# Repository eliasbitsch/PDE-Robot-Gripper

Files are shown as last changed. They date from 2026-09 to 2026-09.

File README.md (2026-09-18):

# Robot Gripper - Part B

A two-finger gripper for an automated production cell, designed as a semester
project for *Produktdesign und Produktentwicklung*, MRE WS 2026/27.

A robot picks a PA 6 part off a buffer belt at 1000 mm, carries it 1800 mm and
places it on a workpiece carrier at 1300 mm. Cycle time is 5 seconds per part.
The part is given; the gripper is not.

**Team:** Bitsch Elias · Ovdiienko Viktoriia - Group 10
**Plan:** [PLAN.md](PLAN.md) · **Status:** concept phase, design freeze 4 Oct 2026

---

## 🔩 The part

| | |
|---|---|
| Bounding box | 95 × 100 × 80 mm |
| Volume | 528.5 cm³ |
| Material | PA 6, ρ = 1140 kg/m³ |
| Mass | 0.602 kg |
| Surface | Ra 1.6 |

Two flat, parallel side faces 70 mm apart, 6200 mm² on the smaller side. The
assignment allows gripping **from the side only** - no undergripping on the
belt, which rules out both a vacuum cup and anything that reaches underneath.

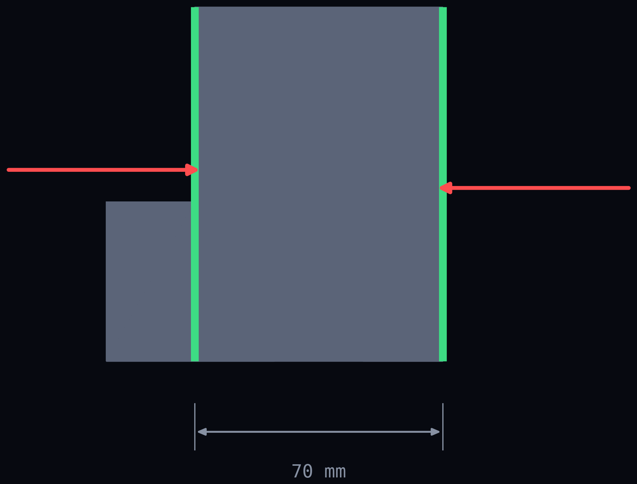
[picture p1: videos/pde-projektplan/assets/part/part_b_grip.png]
Top view of part B with both grip faces marked


---

## The concept

A **2-finger parallel gripper**, one **four-bar parallelogram per finger**,
driven by a single **servo motor** through a self-locking screw.

The design is **inspired by the Robotiq 2F-85**: electric, two fingers, one
four-bar per finger, pads that stay parallel. What we do not take over is its
underactuated adaptive wrap - in encompassing mode that is statically
indeterminate, and on two flat faces it buys nothing.

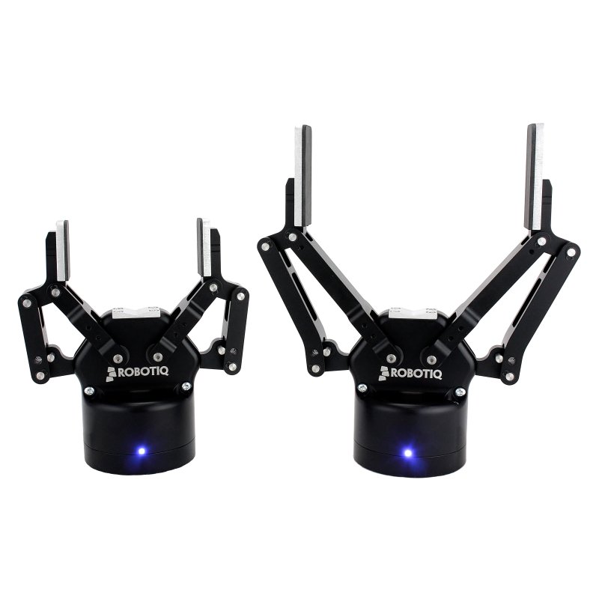
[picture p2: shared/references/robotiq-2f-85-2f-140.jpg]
Robotiq 2F-85 and 2F-140 adaptive grippers


*Robotiq 2F-85 and 2F-140. Photo: Robotiq Inc., used as a design reference.*

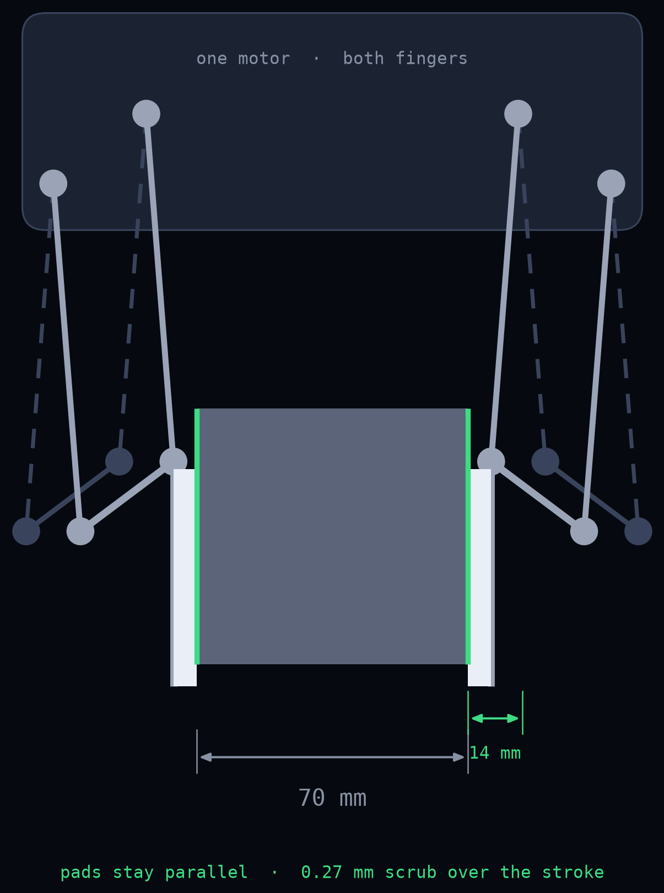
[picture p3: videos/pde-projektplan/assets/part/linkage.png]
Our four-bar linkage, open and closed


*Our version: links 90 mm, swing +-4.46 degrees, 14 mm stroke per side.*

Why this and not a rack:

- **Pads stay parallel** through the four-bar, so the flat faces stay in full contact
- **The screw is self-locking** - the part holds on power failure, no brake needed
- The tip travels on an arc, but with 90 mm links and ±4.46° of swing that is
  **0.27 mm of scrub** over the full 14 mm stroke per side

The price, stated honestly: jaw force is **not constant** over the stroke. The
worst transmission angle has to be proven, not assumed.

**Required gripping force:** 14.3 N per jaw (µ = 0.5 NBR/PA 6, safety factor 2.0,
path acceleration 2.05 m/s² out of the cycle-time budget).

---

## 🤖 The cell

Robot is an **ABB IRB 1600-6/1.45**. The interesting finding from the placement
study: with the robot centred on the floor the sequence is **not executable** -
not because of reach, but because of axis 5 (±115°). With the arm extended high
and far the forearm points steeply up and the tool can no longer be brought
vertical. The fix is a **500 mm pedestal plus a 100 mm base offset** toward the
workpiece carrier. That goes into the report as a finding, not hidden.

---

## 🛠 Toolchain

| Tool | Used for |
|---|---|
| **Onshape** | parametric CAD and FEM on the same model |
| **LaTeX** | calculations and the written report |
| **MuJoCo** | motion sequence, collision check, contact forces |
| **build123d / gmsh / CalculiX** | scripted geometry and the independent FEM cross-check |
| **FDM printing** | a printed jaw, loaded and measured, as a third data point against the FEM |

---

## Repository layout

```
├─ Elias/            system & numerical proof
├─ Viktoriia/        design & analytical proof
├─ shared/
│  ├─ submission/    final structure per Fig. 2 - German names, prescribed
│  └─ references/
├─ videos/           plan pitch video (HyperFrames)
├─ cad/ fem/ sim/    preliminary script chain, kept as reference
└─ PLAN.md
```

Each of us commits only inside our own folder, so there are no merge conflicts.
Merging happens once, at the end, in `shared/submission/`.

The four folder names under `shared/submission/` stay German on purpose - the
assignment prescribes that structure verbatim.

---

## 📅 Dates

| | |
|---|---|
| Design freeze | 4 Oct 2026 |
| Interim report | **26 Nov 2026** |
| Final review | **15 Jan 2027** |

Both are BB-1 dates. We are in different course groups and run on the earlier
schedule deliberately - see open point 0 in the plan.

---

## Grading

100 points across nine packages. The 3D design carries 20 on its own, every
other package 10. The full breakdown, the milestone plan and the open questions
are in [PLAN.md](PLAN.md).

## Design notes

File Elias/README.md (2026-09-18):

# Elias - system & numerical proof

Working area of Bitsch Elias. See [PLAN.md](../PLAN.md), § 5.

| Folder | Package | Result |
|---|---|---|
| `01_Robot` | E1 | Robot selection, placement study (500 mm pedestal + 100 mm base offset), reachability proof |
| `02_CAD_Body` | E2 | Housing, drive unit (servo + self-locking screw), four-bar with bearings, quick-change coupler, robot flange |
| `03_Drawing` | E3 | A3 assembly drawing + BOM |
| `04_Simulation` | E4 | MuJoCo model, path pick -> place, collision log, sequence video |
| `05_FEM` | E5 | Mesh, boundary conditions, mesh convergence, stress and deflection; compared against V4 |

Plus E6: infrastructure (repo, Onshape document, MCP integration, parameter table) in `../shared/`.

**Interface to Viktoriia:** the mounting plane carrier <-> jaw.
Frozen from week 41, changes only together.

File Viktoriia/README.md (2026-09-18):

# Viktoriia - design & analytical proof

Working area of Ovdiienko Viktoriia. See [PLAN.md](../PLAN.md), § 5.

| Folder | Package | Result |
|---|---|---|
| `01_Concept` | V1 | Variant comparison (VDI 2225) incl. the Robotiq 2F-85 as commercial reference and vacuum as a reasoned rejection, dimensioned concept sketch |
| `02_Sizing` | V2 | Gripping force, friction coefficient with a source, surface pressure on PA 6, four-bar via virtual work incl. worst transmission angle, screw and motor selection |
| `03_CAD_Jaws` | V3 | Jaws + soft pads, parametric in Onshape |
| `04_Analytical` | V4 | Bending stress and deflection by hand - the reference the FEM has to meet |
| `05_Print_Check` | V5 | Print the jaw, measure deflection under a defined load, hold it against Elias' FEM |

**The thread:** you design the jaws, work them out by hand, and then check the
FEM against a printed part. V3 -> V4 -> V5 is one chain.

**Interface to Elias:** the mounting plane carrier <-> jaw.
Frozen from week 41, changes only together.

**If something does not suit you:** § 10 in PLAN.md. V3<->E2 and V4<->E5 are cut
to be exchangeable on purpose.

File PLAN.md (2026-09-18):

# Project Plan - Robot Gripper, Part B

**Course:** Produktdesign und Produktentwicklung, MRE WS 2026/27
**Group:** 10 · **Part:** B (PA 6, Ra 1.6)
**Team:** Bitsch Elias · Ovdiienko Viktoriia
**Course groups:** split (BB-1 / BB-2) - interim report and final submission run **together on BB-1**
**Status:** 18 Sep 2026 - proposal, not yet agreed

> **Working language is English** - this plan, the repo, folder names and commit
> messages. Two exceptions, both deliberate: the submission folder names under
> `shared/submission/` stay **German**, because the assignment prescribes them
> verbatim; and the language of the submitted report itself still has to be
> confirmed with Saliger (see open point 5).

---

## 1. What this is

A robot picks part B off the buffer belt (1000 mm), travels 1800 mm
horizontally and places it on a workpiece carrier (1300 mm). Cycle time 5 s per
part. We design the gripper for it - the part itself is given and is not
modified.

Nine deliverables, listed in § 3, submitted in the folder structure from Fig. 2
of the assignment.

---

## 2. Technical decisions

Six decisions. If Viktoriia sees any of them differently, **now** is the moment.
After the design freeze in week 40 every change costs half the chain.

> **Changed 15 Sep 2026:** the mechanism was rack-and-pinion first. The variant
> comparison in `cad/mechanismus.py` only had directly-translating pusher
> mechanisms in the field - rack, wedge hook, trapezoidal screw. The whole
> family of linkages was missing. With the four-bar added the result flips,
> above all on the criterion "holding on power failure": a self-locking screw
> removes the holding brake that the rack made mandatory.

| Topic | Decision | Why |
|---|---|---|
| **Gripping concept** | 2-finger parallel gripper with jaws | Part B has two flat, parallel side faces 70 mm apart. No form fit needed, friction is enough. |
| **Mechanism** | **Four-bar parallelogram per finger**, one motor drives both | Inspired by the Robotiq 2F-85 (see below). Pads stay parallel, the tip travels on an arc. Without the original's underactuation - in encompassing mode that is statically indeterminate and buys nothing on two flat faces. |
| **Drive** | **Servo motor** with self-locking screw or worm | Adjustable force (PA 6 is soft, Ra 1.6 has to survive), quiet, no compressed air. **Self-locking → no holding brake.** That was mandatory with the rack. |
| **CAD + FEM** | **Onshape** (parametric, browser-based) | Both of us in the same model live, no version conflicts, no local install. FEM on the same model, no export break. |
| **Calculation / docs** | **LaTeX** | Formulas, units and cross-references stay consistent; the report is worth 10 points and grows from M1 on. |
| **Simulation** | **MuJoCo** | See § 4. |

### Inspired by the Robotiq 2F-85

Robotiq 2F-85 and 2F-140

*Robotiq 2F-85 and 2F-140. Photo: Robotiq Inc. Source and data in
[`shared/references/SOURCES.md`](shared/references/SOURCES.md).*

What we take from it: electric drive, two fingers, one four-bar parallelogram
per finger so the pads stay parallel while the fingertip travels on an arc.

What we leave out: the underactuated second phalanx. Its adaptive wrap is
statically indeterminate in encompassing mode, which makes the force
distribution between the phalanges hard to prove - and on two flat parallel
faces it adds nothing.

It also settles the force question. A 2F-85 delivers 20-235 N; we need 14.3 N.
Nothing about this concept is force-limited.

### Figures from the preliminary work (to be confirmed, not fixed)

- Part B: 95 × 100 × 80 mm, 528.5 cm³, PA 6 (ρ = 1140 kg/m³) → **0.602 kg**
- Grip faces: ±X, jaw distance **70 mm**, 6200 mm² on the smaller side
- Path acceleration from the cycle-time budget: **2.05 m/s²**
- Required gripping force: **14.3 N per jaw** (µ = 0.5 NBR/PA 6, S = 2.0)
- Starting geometry of the four-bar (to be confirmed in V2): link length
  **90 mm**, swing **±4.46°** about the perpendicular to the grip direction,
  stroke **14 mm per side** → **0.27 mm** pad scrub over the stroke. Longer
  links reduce it further (120 mm → 0.20 mm), shorter ones raise it
  (40 mm → 0.62 mm).
- Reference Robotiq 2F-85: electric 24 V, **20-235 N**, 85 mm stroke, 5 kg
  payload, ~1.3 kg, flange ISO 9409-1-50-4-M6. Force is not the bottleneck in
  any variant - we need 14.3 N.
- Robot: **ABB IRB 1600-6/1.45**
- Most important finding: with the robot centred on the floor the sequence is
  **not executable** - not because of reach, but because of axis 5 (±115°).
  Fix: **500 mm pedestal + 100 mm base offset**. That belongs in the report as
  a finding, not hidden.

### Vacuum was considered and rejected

Physically it would work: a 50 mm cup at −0.6 bar gives ~118 N normal, ~59 N in
shear against the needed 14.3 N. It fails on the assignment, not on the
physics. The assignment prescribes jaws verbatim -

> "Die **Greiferzangen** sind an das jeweilige Bauteil anzupassen und mit einem
> Schnellwechselsystem auszuführen."

and 30 of 100 points hang on a *Greiferzange* and a *Greifmechanismus* that a
suction cup does not have. On top of that, parts can be gripped **from the side
only**, which loads a cup in shear and peeling, its weakest mode; an ejector
needs the compressed air we avoided; and vacuum does not hold on power failure.
This goes into V1 as a reasoned rejection - a comparison that rules out an
obvious option cleanly is worth more than one that never raised it.

---

## 3. What the points are for

100 points total. The distribution is in the introduction slides and it is the
single most important planning input:

| Work package | Points | Who |
|---|---:|---|
| **3D design of the gripper** | **20** | Elias + Viktoriia |
| General (quality of the technical documentation) | 10 | both |
| Robot selection incl. reasoning | 10 | Elias |
| Concept sketch of the gripper | 10 | Viktoriia |
| Calculation and mechanical design of the gripping mechanism | 10 | Viktoriia |
| Analytical calculation of the jaws | 10 | Viktoriia |
| Numerical calculation of the jaws (FEM) | 10 | Elias |
| Assembly drawing including BOM | 10 | Elias |
| Collision check and visualisation of the sequence | 10 | Elias |

**Grading scale:** ≥88 % very good · ≥75 % good · ≥63 % satisfactory · ≥50 % sufficient · <50 % fail

Two conclusions:

- **The CAD counts double.** It gets the most time and both of us carry it.
- **The documentation alone is worth 10 points**, independent of content. That
  is the cheapest grade in the project, which is why it does not get pushed to
  the end.

### The five warnings from the course leader

From the introduction slides, verbatim - the plan is built around them:

| Warning | How the plan absorbs it |
|---|---|
| 1. Do not start designing without calculating | Gripping force (V2) sits in M1, **before** CAD starts in M2. The design freeze separates them cleanly. |
| 2. Do not start the FEM too late | The FEM (E5) sits in M3 and is done **before** the interim report, not after. |
| 3. Do not underestimate the drawings | Drawing + BOM (E3) starts in December, not January. Two full weeks. |
| 4. Do not start the documentation in the last week | Runs from M1 on. Every package is written **when** it is finished. January is merging only. |
| 5. Take the interim report seriously | Its own milestone with a content list and 4 days of buffer. |

---

## 4. Simulation: MuJoCo over Gazebo

Gazebo would be right if we were driving a real ABB controller through ROS 2
and MoveIt - sensor simulation, plugins, a whole cell. We do not need that. The
assignment asks for "visual representation incl. collision check of the working
sequence": kinematics, collision, and a video.

MuJoCo is the better fit:

- **Runs without ROS**, straight from Python - no stack that eats a week of setup
- **Contact forces** are readable. We can show that the part actually does not
  slip under the calculated gripping force instead of asserting it. That is a
  real argument in the report.
- **Headless rendering** in good quality → images for the report and the video
  come out of the same run
- **It already runs.** `sim/aufstellung.py` and `sim/ablauf.py` work, including
  Levenberg-Marquardt IK with configuration continuity.

Against MuJoCo, Gazebo here has only downsides: heavier, ROS-dependent, on
Windows only through WSL, and no added value for what gets submitted.

---

## 5. Who does what

Two halves, each a closed story. Nobody gets leftovers.

### Elias - system & numerical proof

| # | Package | Result | Folder |
|---|---|---|---|
| E1 | **Robot selection & placement** | Selection calculation (reach, cycle time, payload), placement study for pedestal/base offset, reachability proof for all waypoints | `Elias/01_Robot` |
| E2 | **Gripper body** | Housing, drive unit (servo + self-locking screw), four-bar with bearings, quick-change coupler, robot flange ISO 9409-1-50-4-M6 | `Elias/02_CAD_Body` |
| E3 | **Assembly drawing & BOM** | A3 drawing, item numbers, BOM split into bought and made parts | `Elias/03_Drawing` |
| E4 | **Motion & collision study** | MuJoCo model, path pick → place, collision log, sequence video | `Elias/04_Simulation` |
| E5 | **FEM of the jaws** | Mesh, boundary conditions, mesh convergence, stress and deflection; compared against Viktoriia's analytical result | `Elias/05_FEM` |
| E6 | **Infrastructure** | Repo, Onshape document, MCP integration, parameter table, report template | `shared/` |

### Viktoriia - design & analytical proof

| # | Package | Result | Folder |
|---|---|---|---|
| V1 | **Gripping concept & sketch** | Variant comparison to VDI 2225 - **with the Robotiq 2F-85 as a commercial reference in the field**, plus four-bar, rack, wedge hook, screw, and vacuum as a reasoned rejection. Dimensioned concept sketch | `Viktoriia/01_Concept` |
| V2 | **Gripping force & drive sizing** | Force balance (weight + acceleration + safety), friction coefficient with a source, surface pressure on PA 6, **four-bar via virtual work including proof of the worst transmission angle**, screw sizing incl. self-locking, motor selection with margin | `Viktoriia/02_Sizing` |
| V3 | **Jaws & soft pads (CAD)** | Parametric jaws in Onshape, pad pocket, contour matched to part B | `Viktoriia/03_CAD_Jaws` |
| V4 | **Analytical strength proof** | Bending stress and deflection of the jaw by hand, assumptions and sources documented - the reference the FEM has to meet | `Viktoriia/04_Analytical` |
| V5 | **3D-printed check** | Print the jaw, measure deflection under a defined load, hold it against Elias' FEM | `Viktoriia/05_Print_Check` |

**Why this cut:** Viktoriia designs the jaws and works them out by hand. Elias
recomputes the same jaws numerically. Two people check the same part on two
independent paths - exactly what the assignment asks for, and a discrepancy
shows up immediately instead of hiding in one pair of hands.

The printed check (V5) sits with Viktoriia for the same reason: whoever ran the
FEM should not confirm it themselves.

The interface between the two halves is a single surface: the **mounting plane
carrier ↔ jaw**. It is fixed in week 41 and not touched afterwards.

### Together

- **Documentation** - each writes their own chapters, mutual review
- **Cross-review** before every milestone: Elias re-checks Viktoriia's
  calculations, Viktoriia checks Elias' model for manufacturability
- **Submission ZIP** in the structure from Fig. 2

---

## 6. The 3D-printing idea

Nobody asks for this - but it is cheap and it lifts the work noticeably.

We print the jaw in PLA/PETG at 1:1, clamp it, hang a defined load on the free
end and **measure the deflection**. Then we recompute the same geometry with the
print material's Young's modulus and compare three numbers: analytical, FEM,
measured.

What it buys:

- The analytical/numerical comparison turns from a box to tick into a real
  result - with a third, physical data point
- It shows immediately whether the clamping in the FEM model was assumed too
  stiff. That is the classic FEM error and we can demonstrate it instead of
  guessing.
- The printed jaw can be shown. A real jaw in your hand beats any rendering.

**For honesty in the report:** we print PLA, we build EN AW-7075. The test
validates the *model* (boundary conditions, load introduction, mesh), not the
part. That is exactly how we write it.

---

## 7. Timeline

### The two hard dates

We are in different course groups but deliver together. We both run on
**BB-1** - the **earlier** dates:

| | Date | Note |
|---|---|---|
| 🔴 **Interim report** | **Thu 26 Nov 2026, 17:50, on site** | BB-1 instead of BB-2 (3 Dec) - one week earlier |
| 🔴 **Final review** | **Fri 15 Jan 2027, 16:10, on site** | BB-1 instead of BB-2 (22 Jan) - one week earlier |

**That costs us a week of buffer each time.** A deliberate choice, but it has to
be cleared with the course leader (Saliger) - whoever is in BB-2 presents in a
group that is not theirs. That is point 0 on the open list.

### Course dates set the rhythm (BB-1)

We put our packages behind the lectures, not in front of them:

| Date | Topic | What it means for us |
|---|---|---|
| Thu 17 Sep | Introduction to Onshape | CAD starts **after** this, not before |
| Sat 19 Sep | Modelling and drawing | Modelling skills in place |
| Tue 22 Sep | BOM, sheet metal, MDB | BOM logic for E3 |
| Sat 24 Oct | Assemblies, data exchange | Lands right inside the CAD phase |
| Wed 4 Nov | Digital validation, simulation | Directly before the simulation phase |
| **Thu 26 Nov** | **Interim report** | 🔴 |
| Wed 2 Dec | CAE-CAD-CAP-CAM process chain | - |
| **Fri 15 Jan** | **Final review, Q&A** | 🔴 |

### Milestones

| Milestone | Deadline | Result | Who |
|---|---|---|---|
| **M0 - Kick-off** | Sun 20 Sep | Plan agreed, roles fixed, Onshape + repo up, open questions sent | both |
| **M1 - Concept fixed** | Sun 4 Oct | Robot chosen (E1), gripping concept + sketch (V1), force calculated (V2) → **design freeze** | both |
| **M2 - CAD closes** | Sun 1 Nov | Jaws (V3) and body (E2) designed separately, assembly closes without collisions, interface frozen | both |
| **M3 - Proofs** | Sun 22 Nov | Analytical done (V4), FEM computed incl. mesh convergence (E5), both paths compared | both |
| 🔴 **Interim report** | **Thu 26 Nov** | Presentation: concept, sizing, CAD, first proofs | both |
| **M4 - Drawing + simulation + print** | Sun 20 Dec | Assembly drawing + BOM (E3), MuJoCo sequence + collision log + video (E4), jaw printed and measured (V5) | parallel |
| *Christmas break* | 21 Dec - 3 Jan | - | - |
| **M5 - Merge** | Sun 11 Jan | Documentation merged, cross-review, ZIP packed | both |
| 🔴 **Final review** | **Fri 15 Jan** | ZIP uploaded, on-site date | both |

**Buffer:** 4 days before the interim report, 4 days before the final review.
That is tight. Which is why the FEM chain sits **before** the interim report and
not after - if something goes wrong there we still have December.

**The drawing sits in December on purpose, not January.** Warning 3. Two weeks
for drawing and BOM is realistic, not generous.

**Documentation runs from M1.** Every package is written when it is done, not at
the end. M5 is merging and proofreading - no writing. That is warning 4, and it
is worth 10 points.

**Standing appointment:** a short sync every week, 20 minutes, status +
blockers.

---

## 8. Open points

These need clearing early, because they get expensive later:

0. **Split course groups.** We are in BB-1 and BB-2 but want to run on BB-1
   together (interim report 26 Nov, final review 15 Jan). Reassuring: per the
   introduction slides **at least one person per group** has to attend the
   interim report and the final review - not both. Still, clear with Alexandra
   Saliger whether attendance in the other cohort counts. On top of that there
   is **75 % attendance duty**, counted in your own group. **Clear this before
   anything else.**
1. **Group number.** `task.md` says group 10, Tab. 1 of the assignment only
   knows groups 1-8 (part B = group 2). Ask the course leader before any
   document is printed with a number in its header.
2. **Placement orientation on the workpiece carrier.** Per the assignment this
   is defined at the assignment handout. Currently assumed as a 90° rotation. A
   different orientation changes the path and possibly the grip direction.
   **This is the only open point that can still break the design freeze.**
3. **FDM printer.** Clear availability and material (lab or private).
4. **Transmission angle.** With a four-bar the jaw force is **not** constant
   over the stroke. The worst point has to be proven - that is the price of the
   topology and it belongs in V2, not at the end.
5. **Pad scrub on the grip face.** 0.27 mm over the stroke at 90 mm links.
   Prove for Ra 1.6 on PA 6 that the soft pad absorbs it elastically.
6. **Onshape FEM.** Check whether the education plan unlocks Simulation. If not,
   the existing CalculiX chain steps in - equivalent result, more manual work.
7. **Onshape licence.** The free plan makes documents public. For student work
   that is usually fine, but it should be a conscious choice - the education
   plan is free and private.
8. **Language of the submitted report.** The course, the assignment and the
   slides are German. Our working language is English. Confirm with Saliger
   which language the submitted documentation should be in - this does not
   affect the repo either way.

---

## 9. How we work in the repo

```
PDE/
├─ Elias/            ← Elias commits only here
├─ Viktoriia/        ← Viktoriia commits only here
├─ shared/           ← parameters, templates, submission ZIP
│  ├─ submission/    ← final structure per Fig. 2 - German names, prescribed
│  └─ references/
├─ videos/           ← the plan pitch video (HyperFrames project)
├─ cad/ fem/ sim/    ← existing script chain (preliminary work, kept as reference)
└─ PLAN.md
```

**Rule:** each of us commits only inside our own folder. Then there are no merge
conflicts. Merging happens exclusively in `shared/submission/`, at the end,
deliberately and together.

Commit messages in English, one line, what changed and why.

**`shared/submission/` keeps its German folder names on purpose.** The
assignment says the structure is to be used *exclusively* as given, so those
four names are copied verbatim and must not be translated:

```
1. Dokumentation und Berechnung
2. Konstruktionsdaten (3D-CAD-Daten)
3. Baugruppenzeichnung (Greifer)
4. Kollisionskontrolle und Bewegungsanalyse
```

---

## 10. What Viktoriia should say about this

This is a **proposal**, not a decision. Feedback wanted specifically on:

- Does the split work? If you would rather do CAD than the analytical part (or
  the other way round), we swap - the packages are cut so V3↔E2 and V4↔E5 are
  exchangeable.
- Onshape fine, or would you rather work in something else? (SolidWorks,
  Fusion, Inventor - then we only need to settle the interface via STEP.)
- Is the timeline too tight or too loose?
- The FEM moved to Elias on purpose so your side does not overflow. You compute
  analytically, he computes numerically. If you would rather run the FEM
  yourself, we swap back.

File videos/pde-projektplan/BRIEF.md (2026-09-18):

---
workflow: general-video
flow: automation
storyboard: no
message: "The plan is set - tell me what you'd change"
destination: file
aspect: 1920x1080
language: en
audience: "Viktoriia, project partner, mechanical engineering student"
length: 87s
angle: plan-pitch
---

## Intent

Pitch video for Viktoriia. In under a minute and a half she should see: what we
grip and where, why a 2-finger four-bar gripper with a servo, which tool does
what, which two dates are hard, what each package is worth, who takes what, and
the route from September to January.

Tone: collegial and concrete, no marketing. It is a proposal, not a decision -
the ending explicitly invites her to push back. Technical, dark, precise. No
voiceover, no music bed: she will most likely watch it muted on a phone.

Per the author: **timeline and task split are the core scenes.** The toolchain
is the surprise, not the main content. Points per package must be visible so it
is clear what is worth what.

## Assets

- `assets/part/part_b.png` - part B, isometric, tessellated from Bauteil_B.STEP via build123d
- `assets/part/part_b_title.png` - same view, used on the title scene
- `assets/part/part_b_grip.png` - top view, both grip faces marked, jaw arrows, 70 mm dimension
- `assets/part/linkage.png` - four-bar schematic drawn from the real geometry (90 mm links, +-4.46 deg, 0.27 mm scrub)
- `assets/part/robotiq.jpg` - Robotiq 2F-85 / 2F-140 product photo, design reference. Copyright Robotiq Inc., credited on screen; source note in shared/references/SOURCES.md
- `assets/shots/onshape.png` - Onshape landing page, advertises FeatureScript MCP itself
- `assets/shots/mujoco.png` - mujoco.org
- `assets/logos/onshape.png`, `mujoco.png`, `latex.svg`, `github.svg` - official marks
- `assets/work/fem_konvergenz.png`, `ablauf_4_transport.png` - own images from the preliminary work

Only assets actually referenced by index.html are kept in the repo.

## Customizations

- Real logos and real website screenshots instead of rebuilt tiles - explicitly requested.
- Own working images included so it is visible that the chain already runs.
- The two red deadlines (26 Nov / 15 Jan) must read as the hardest thing on screen.
- Points shown per package, matching the Moodle breakdown exactly.
- Ending with the repo link and an explicit invitation to disagree.

## Notes

- English throughout, including the repo name.
- No invented numbers. Points, dates and figures come from `moodle/` and `PLAN.md`.
- Viktoriia is in course group BB-2, Elias in BB-1 - the video does not claim
  the date question is settled, it names it as open.

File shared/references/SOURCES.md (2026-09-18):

# Sources for third-party material

## robotiq-2f-85-2f-140.jpg

Product photo of the Robotiq 2F-85 and 2F-140 adaptive grippers.
Copyright Robotiq Inc. Used here as a design reference and for the variant
comparison in V1, with attribution. Not our own work, not to be presented as
such in the report.

Product page: https://robotiq.com/products/adaptive-grippers

Key data used in the plan (2F-85): electric, 24 V DC, grip force 20-235 N,
stroke 85 mm, payload 5 kg, mass ~1.3 kg, flange ISO 9409-1-50-4-M6.
Sources: unchainedrobotics.de, roboticscenter.ai, PAL Robotics SDK docs.

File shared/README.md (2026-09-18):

# Shared

| Folder | Contents |
|---|---|
| `submission` | final submission structure per Fig. 2 of the assignment, filled at the end |
| `references` | datasheets, standards, literature, sources for friction coefficients and material data |

The shared parameter table and the report template live here too.

**Rule:** `submission/` is merged only at the end, deliberately and together.
Until then everyone works in their own folder.

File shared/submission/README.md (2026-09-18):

# Submission structure - do not rename

The assignment states that this structure is to be used **exclusively** as
given. The four folder names below are copied verbatim from Fig. 2 and stay
German, even though the rest of the repo is English:

    1. Dokumentation und Berechnung
    2. Konstruktionsdaten (3D-CAD-Daten)
    3. Baugruppenzeichnung (Greifer)
    4. Kollisionskontrolle und Bewegungsanalyse

The ZIP is named `Gruppe-X-PDE-Projekt-WS24.zip` per Fig. 2 - the group number
is still open, see PLAN.md open point 1.

Unless stated otherwise the documents go in as PDF. Put both names and the group
number in every single document.

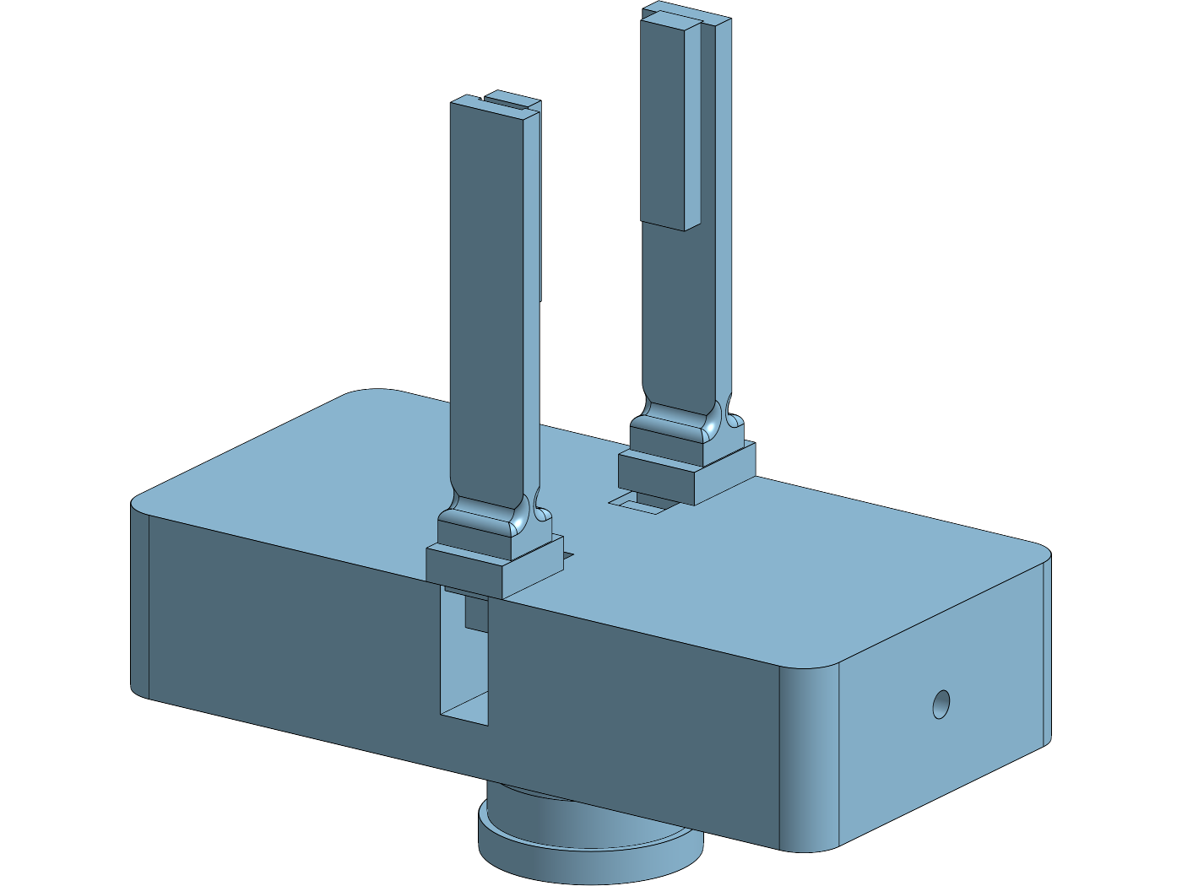
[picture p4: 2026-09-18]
out/bilder/onshape_design_zu.png

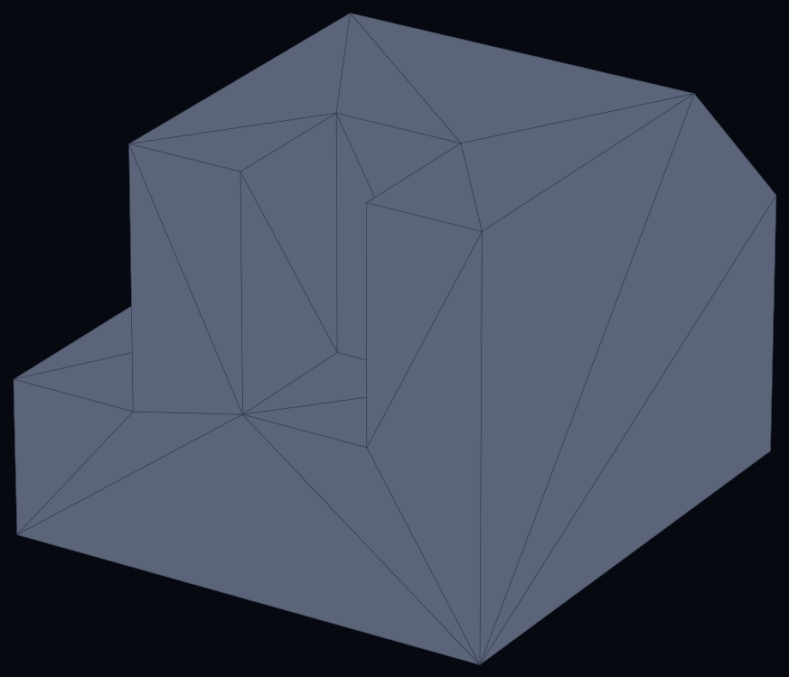
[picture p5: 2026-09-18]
videos/pde-projektplan/assets/part/part_b.png

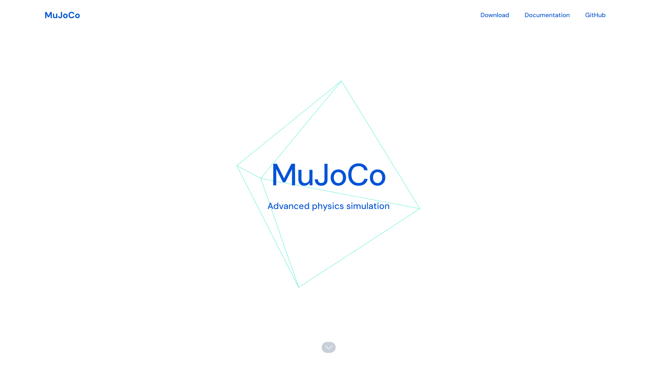
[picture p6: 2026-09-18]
videos/pde-projektplan/assets/shots/mujoco.png

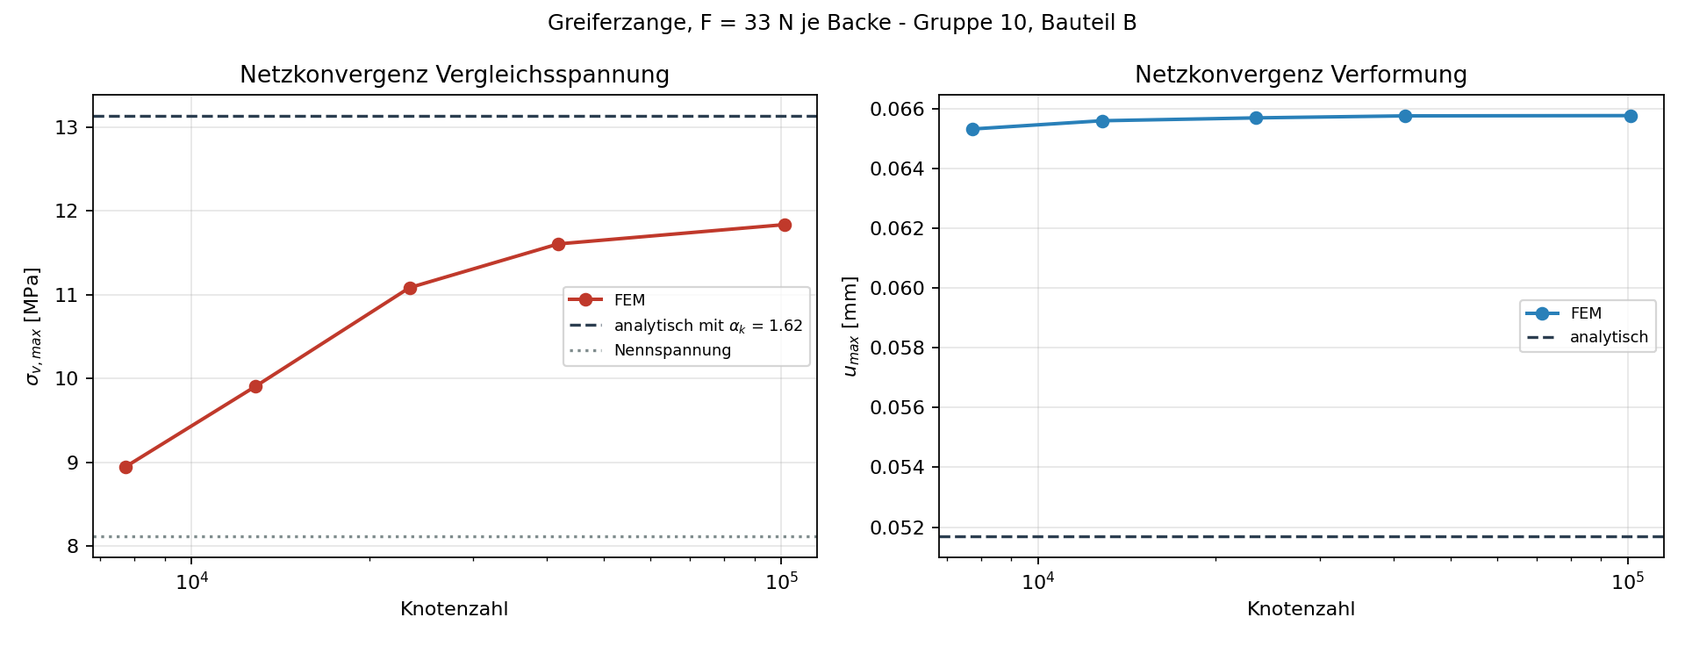
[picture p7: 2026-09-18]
videos/pde-projektplan/assets/work/fem_konvergenz.png

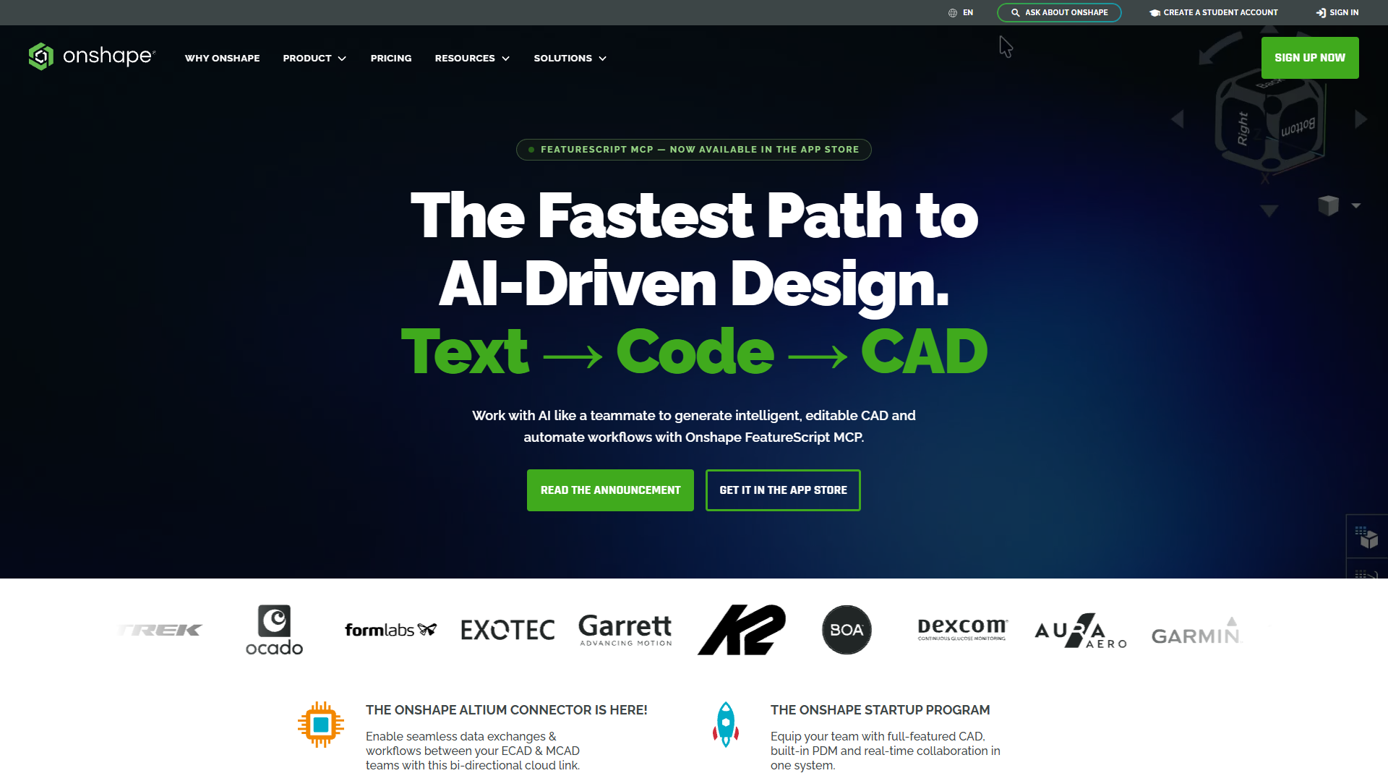
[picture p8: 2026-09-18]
videos/pde-projektplan/assets/shots/onshape.png

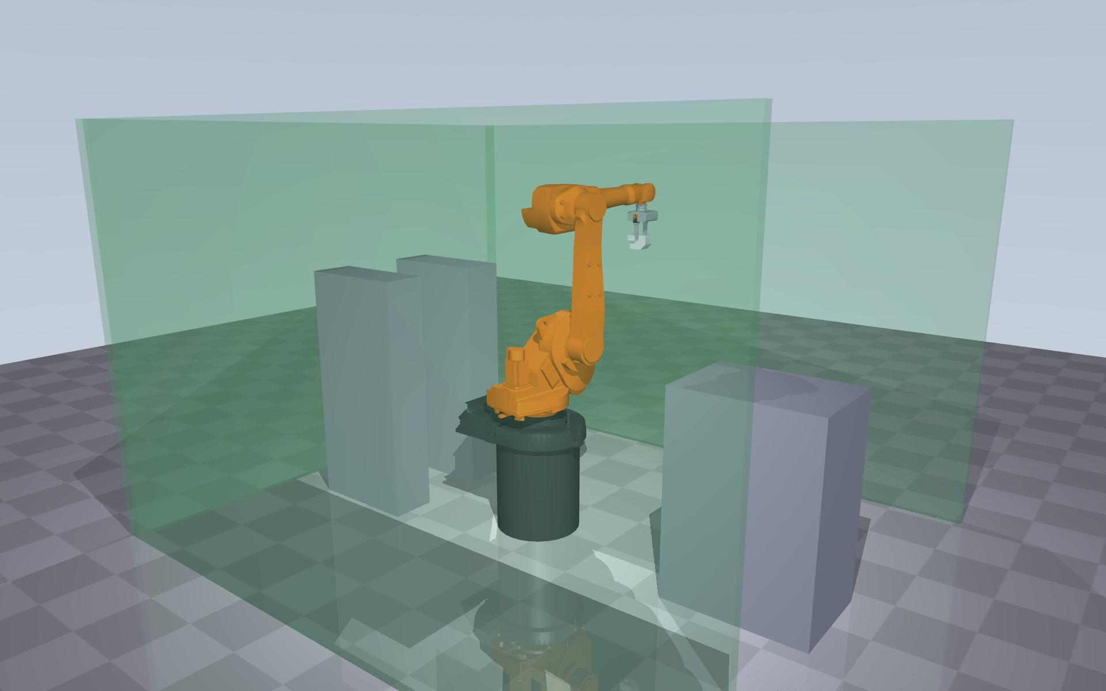
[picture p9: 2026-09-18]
videos/pde-projektplan/assets/work/ablauf_4_transport.png

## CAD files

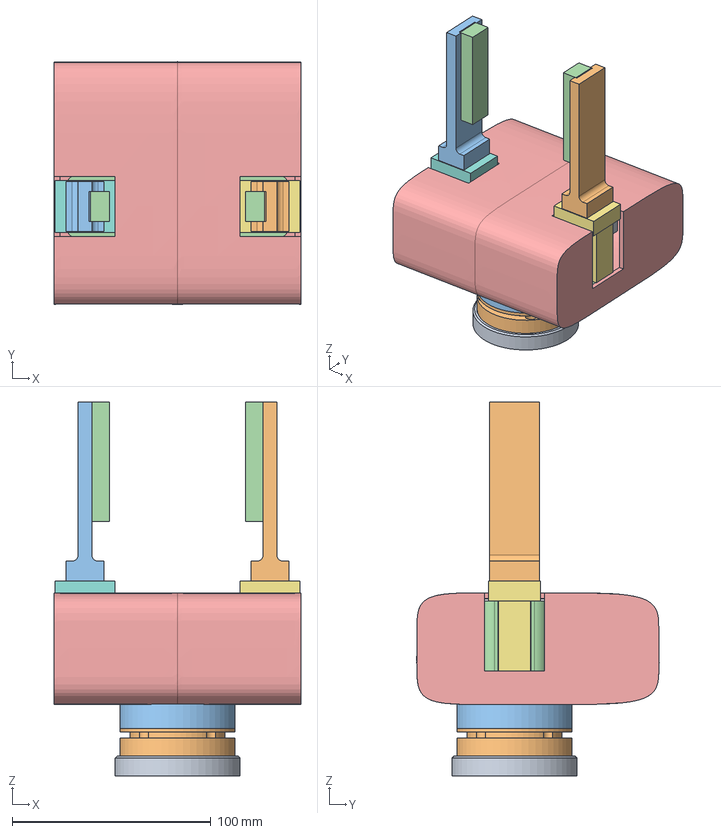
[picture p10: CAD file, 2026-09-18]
out/step/Greifer_Baugruppe.step
124.0 x 121.9 x 188.0 mm
Pos1_Adapterplatte
Pos2_Schnellwechsler_Roboterseite
Pos3_Schnellwechsler_Greiferseite
Pos4_Funktionstraeger
Pos5_Ritzel_m=1_z=20
Pos6_Ritzelwelle
Pos7_Zahnstange_mit_Backenflansch_L
Pos7_Zahnstange_mit_Backenflansch_R
Pos8_Servomotor_mit_Planetengetriebe
Pos9_Greiferzange_L
Pos9_Greiferzange_R
Pos10_Weichbacke_L
Pos10_Weichbacke_R
Pos11_Verkleidung
Pos12_Haltebremse_am_Ritzel

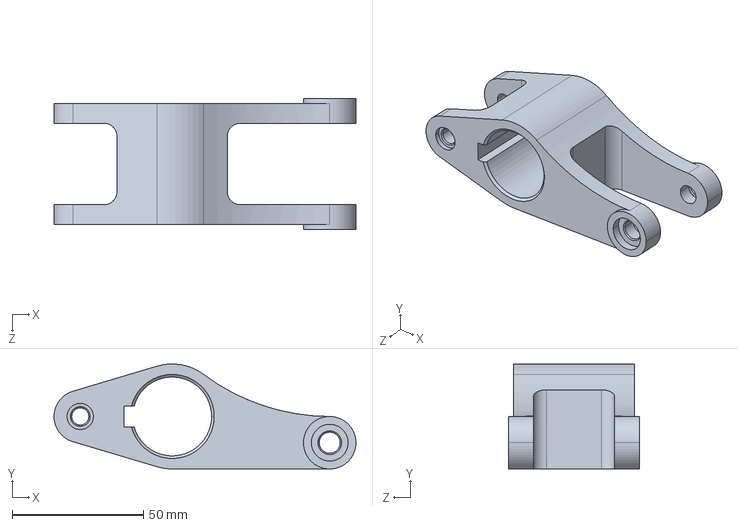
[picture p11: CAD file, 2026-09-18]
3D-Daten der Bauteile-20260904/Bauteil_C.STEP
115.0 x 40.0 x 50.0 mm

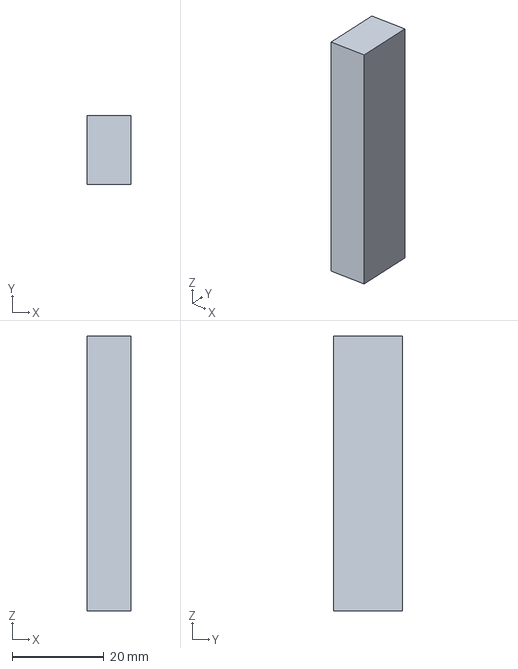
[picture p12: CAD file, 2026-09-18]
out/step/Pos11_Weichbacke_R.step
9.50 x 15.0 x 60.0 mm

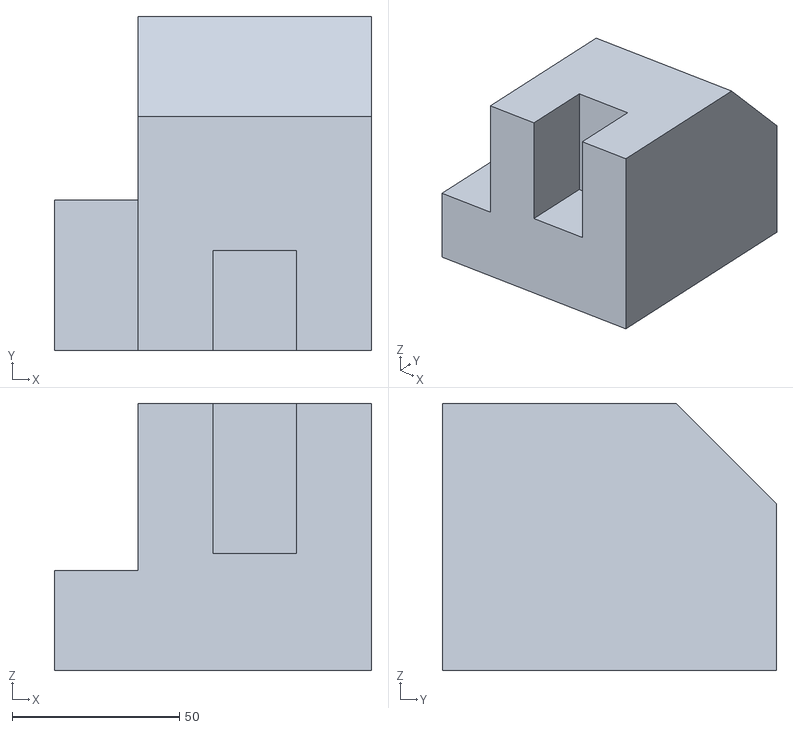
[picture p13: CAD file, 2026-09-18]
sim/meshes/bauteil_B.stl
95.0 x 100.0 x 80.0

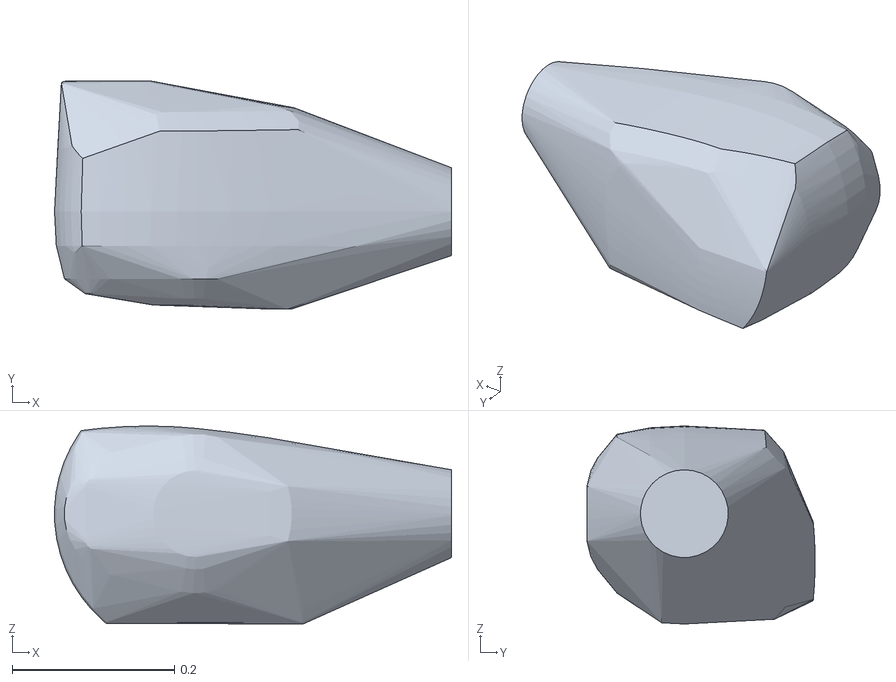
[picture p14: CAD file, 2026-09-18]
sim/meshes/irb1600/collision/link_3.stl
0.489 x 0.281 x 0.244

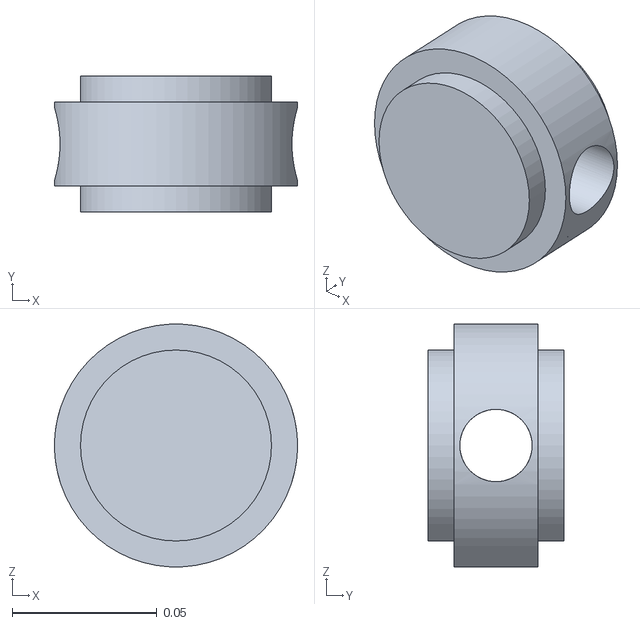
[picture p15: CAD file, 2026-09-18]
sim/meshes/irb1600/visual/link_5.stl
0.084 x 0.047 x 0.0839

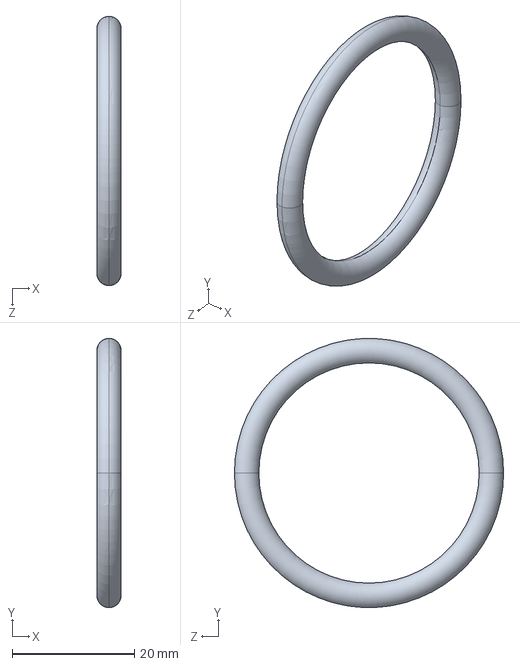
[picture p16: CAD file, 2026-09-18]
3D-Daten der Bauteile-20260904/Bauteil_G.STEP
4.00 x 44.0 x 44.0 mm

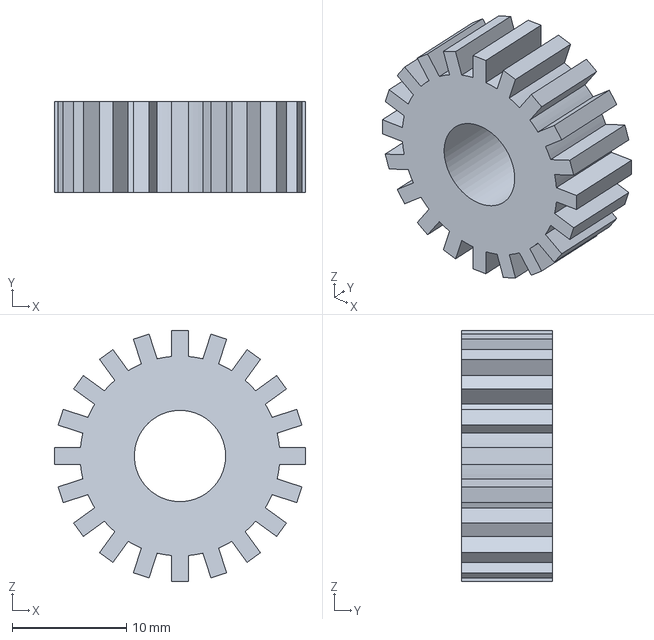
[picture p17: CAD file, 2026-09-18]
out/step/Pos5_Ritzel_m=1_z=20.step
22.0 x 8.00 x 22.0 mm

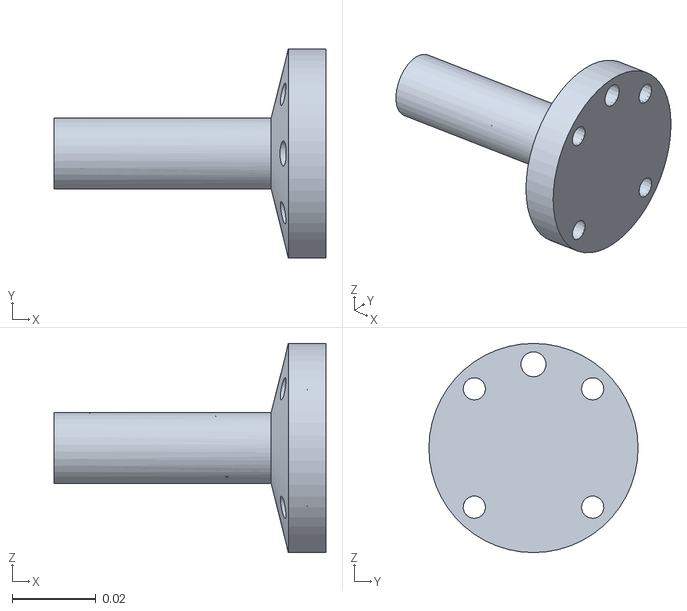
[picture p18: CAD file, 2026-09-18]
sim/meshes/irb1600/collision/link_6.stl
0.065 x 0.05 x 0.05

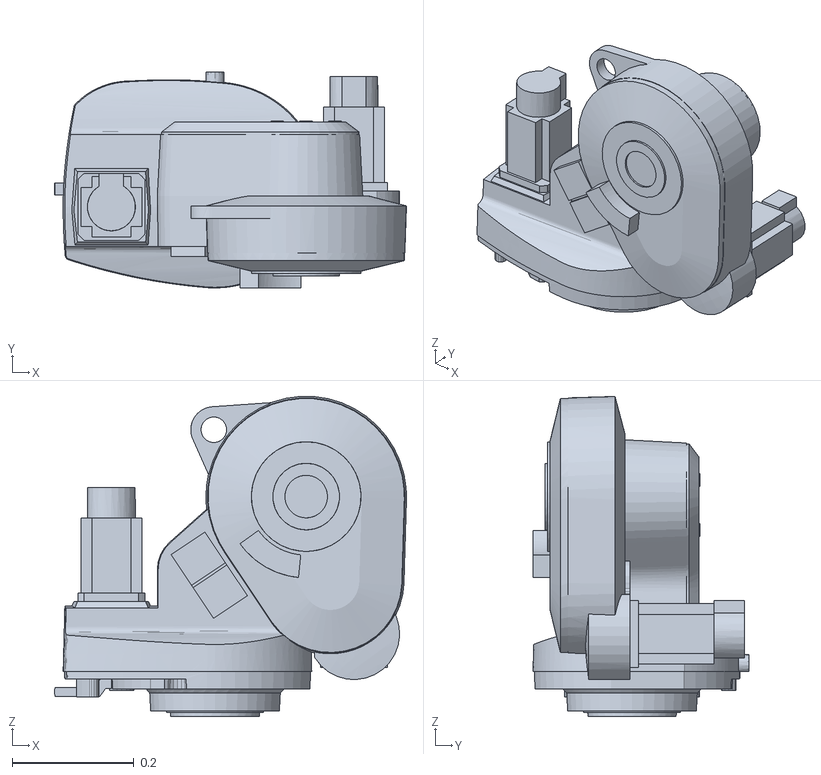
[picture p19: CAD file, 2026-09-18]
sim/meshes/irb1600/visual/link_1.stl
0.579 x 0.356 x 0.527

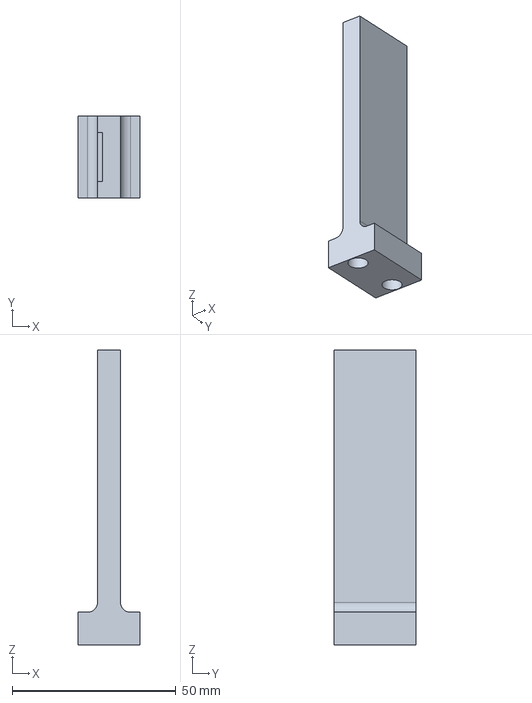
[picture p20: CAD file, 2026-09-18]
out/step/Greiferzange_FEM.step
19.0 x 25.0 x 90.0 mm

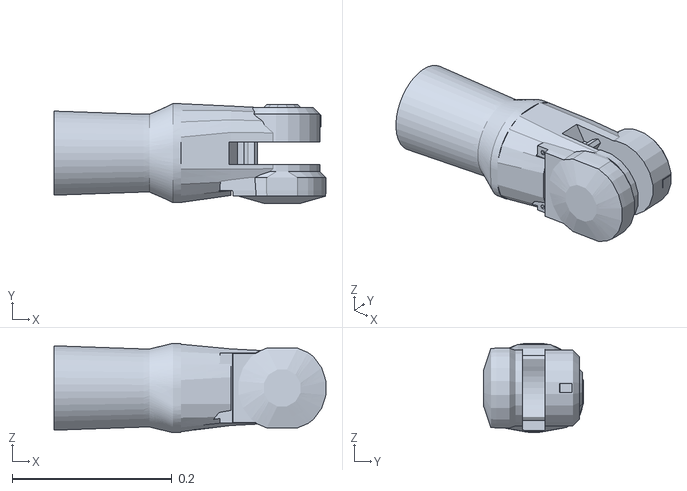
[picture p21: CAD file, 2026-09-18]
sim/meshes/irb1600/collision/link_4.stl
0.341 x 0.125 x 0.112

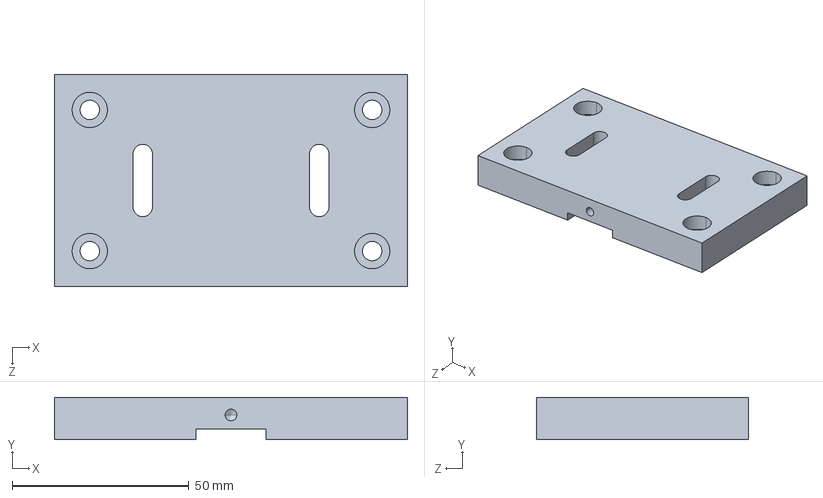
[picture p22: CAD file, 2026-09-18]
3D-Daten der Bauteile-20260904/Bauteil_A.STEP
100.0 x 12.0 x 60.0 mm

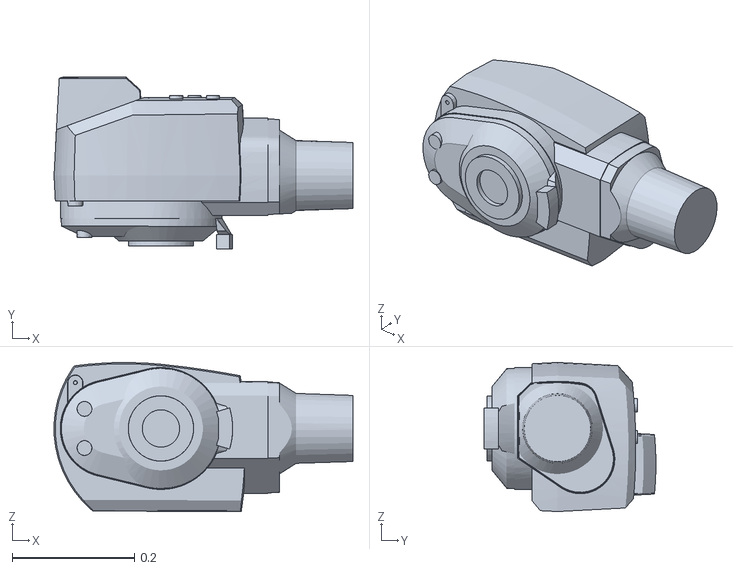
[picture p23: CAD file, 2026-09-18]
sim/meshes/irb1600/visual/link_3.stl
0.489 x 0.281 x 0.244

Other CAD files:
3D-Daten der Bauteile-20260904/Bauteil_B.STEP
3D-Daten der Bauteile-20260904/Bauteil_F.STEP
3D-Daten der Bauteile-20260904/Bauteil_D.STEP
3D-Daten der Bauteile-20260904/Bauteil_E.STEP
3D-Daten der Bauteile-20260904/Bauteil_H.STEP
out/step/Pos10_Greiferzange_L.step
out/step/Pos10_Greiferzange_R.step
out/step/Pos10_Weichbacke_L.step
out/step/Pos10_Weichbacke_R.step
out/step/Pos11_Verkleidung.step
out/step/Pos11_Weichbacke_L.step
out/step/Pos12_Haltebremse_am_Ritzel.step
out/step/Pos1_Adapterplatte.step
out/step/Pos2_Schnellwechsler_Roboterseite.step
out/step/Pos3_Schnellwechsler_Greiferseite.step
out/step/Pos4_Funktionstraeger.step
out/step/Pos4_Greifergehaeuse.step
out/step/Pos4_Greifergrundkoerper.step
out/step/Pos5_Schlitten_Grundbacke.step
out/step/Pos5_Zylinderdeckel.step
out/step/Pos6_Greiferzange.step
out/step/Pos6_Kolben_mit_Kolbenstange.step
out/step/Pos6_Ritzelwelle.step
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

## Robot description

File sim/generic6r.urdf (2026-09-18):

<?xml version='1.0'?>
<robot name='generic6r'>
  <link name="base">
    <visual><origin xyz="0 0 0.2"/>
      <geometry><cylinder radius="0.16" length="0.4"/></geometry>
      <material name="m_base"><color rgba="0.25 0.25 0.28 1"/></material></visual>
    <collision><origin xyz="0 0 0.2"/>
      <geometry><cylinder radius="0.16" length="0.4"/></geometry></collision>
    <inertial><mass value="5"/><inertia ixx="0.1" iyy="0.1" izz="0.1" ixy="0" ixz="0" iyz="0"/></inertial>
  </link>
  <link name="shoulder">
    <visual><origin xyz="0 0 0.09"/>
      <geometry><cylinder radius="0.13" length="0.18"/></geometry>
      <material name="m_shoulder"><color rgba="1.0 0.45 0.05 1"/></material></visual>
    <collision><origin xyz="0 0 0.09"/>
      <geometry><cylinder radius="0.13" length="0.18"/></geometry></collision>
    <inertial><mass value="5"/><inertia ixx="0.1" iyy="0.1" izz="0.1" ixy="0" ixz="0" iyz="0"/></inertial>
  </link>
  <link name="upperarm">
    <visual><origin xyz="0 0 0.325"/>
      <geometry><cylinder radius="0.1" length="0.65"/></geometry>
      <material name="m_upperarm"><color rgba="1.0 0.45 0.05 1"/></material></visual>
    <collision><origin xyz="0 0 0.325"/>
      <geometry><cylinder radius="0.1" length="0.65"/></geometry></collision>
    <inertial><mass value="5"/><inertia ixx="0.1" iyy="0.1" izz="0.1" ixy="0" ixz="0" iyz="0"/></inertial>
  </link>
  <link name="forearm">
    <visual><origin xyz="0 0 0.275"/>
      <geometry><cylinder radius="0.085" length="0.55"/></geometry>
      <material name="m_forearm"><color rgba="1.0 0.45 0.05 1"/></material></visual>
    <collision><origin xyz="0 0 0.275"/>
      <geometry><cylinder radius="0.085" length="0.55"/></geometry></collision>
    <inertial><mass value="5"/><inertia ixx="0.1" iyy="0.1" izz="0.1" ixy="0" ixz="0" iyz="0"/></inertial>
  </link>
  <link name="wrist1">
    <visual><origin xyz="0 0 0.06"/>
      <geometry><cylinder radius="0.07" length="0.12"/></geometry>
      <material name="m_wrist1"><color rgba="1.0 0.45 0.05 1"/></material></visual>
    <collision><origin xyz="0 0 0.06"/>
      <geometry><cylinder radius="0.07" length="0.12"/></geometry></collision>
    <inertial><mass value="5"/><inertia ixx="0.1" iyy="0.1" izz="0.1" ixy="0" ixz="0" iyz="0"/></inertial>
  </link>
  <link name="wrist2">
    <visual><origin xyz="0 0 0.075"/>
      <geometry><cylinder radius="0.06" length="0.15"/></geometry>
      <material name="m_wrist2"><color rgba="1.0 0.45 0.05 1"/></material></visual>
    <collision><origin xyz="0 0 0.075"/>
      <geometry><cylinder radius="0.06" length="0.15"/></geometry></collision>
    <inertial><mass value="5"/><inertia ixx="0.1" iyy="0.1" izz="0.1" ixy="0" ixz="0" iyz="0"/></inertial>
  </link>
  <link name="flange">
    <visual><origin xyz="0 0 0.02"/>
      <geometry><cylinder radius="0.055" length="0.04"/></geometry>
      <material name="m_flange"><color rgba="0.2 0.2 0.2 1"/></material></visual>
    <collision><origin xyz="0 0 0.02"/>
      <geometry><cylinder radius="0.055" length="0.04"/></geometry></collision>
    <inertial><mass value="5"/><inertia ixx="0.1" iyy="0.1" izz="0.1" ixy="0" ixz="0" iyz="0"/></inertial>
  </link>
  <joint name="A1" type="revolute">
    <parent link="base"/><child link="shoulder"/>
    <origin xyz="0 0 0.4"/><axis xyz="0 0 1"/>
    <limit lower="-3.141592653589793" upper="3.141592653589793" effort="500" velocity="4.0"/>
  </joint>
  <joint name="A2" type="revolute">
    <parent link="shoulder"/><child link="upperarm"/>
    <origin xyz="0 0 0.18"/><axis xyz="0 1 0"/>
    <limit lower="-2.0" upper="2.0" effort="500" velocity="4.0"/>
  </joint>
  <joint name="A3" type="revolute">
    <parent link="upperarm"/><child link="forearm"/>
    <origin xyz="0 0 0.65"/><axis xyz="0 1 0"/>
    <limit lower="-2.6" upper="2.6" effort="500" velocity="4.0"/>
  </joint>
  <joint name="A4" type="revolute">
    <parent link="forearm"/><child link="wrist1"/>
    <origin xyz="0 0 0.55"/><axis xyz="0 0 1"/>
    <limit lower="-3.141592653589793" upper="3.141592653589793" effort="500" velocity="4.0"/>
  </joint>
  <joint name="A5" type="revolute">
    <parent link="wrist1"/><child link="wrist2"/>
    <origin xyz="0 0 0.12"/><axis xyz="0 1 0"/>
    <limit lower="-2.2" upper="2.2" effort="500" velocity="4.0"/>
  </joint>
  <joint name="A6" type="revolute">
    <parent link="wrist2"/><child link="flange"/>
    <origin xyz="0 0 0.15"/><axis xyz="0 0 1"/>
    <limit lower="-3.141592653589793" upper="3.141592653589793" effort="500" velocity="4.0"/>
  </joint>
</robot>

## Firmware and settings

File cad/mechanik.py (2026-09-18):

"""Innere Mechanik des Greifers - Zahnstange-Ritzel, Servomotor.

Wirkprinzip (Variantenvergleich in mechanismus.py):

    Servomotor -> Planetengetriebe i=5 -> Ritzel -> zwei Zahnstangen

Das Ritzel zwingt beide Zahnstangen gegenlaeufig und gleich weit; die Backen
laufen also zwangslaeufig synchron, ohne Regelung und ohne zweiten Antrieb.

WARUM DIE ZAHNSTANGEN UEBEREINANDER LIEGEN

Liegen sie nebeneinander (XY-Ebene), steht die Ritzelachse senkrecht. Ein
NEMA 17 mit Planetengetriebe und Haltebremse ist rund 110 mm lang und wuerde
koaxial entweder nach oben in den Roboterflansch (nur 40 mm Platz) oder nach
unten ins Bauteil (nur 80 mm Platz) ragen. Beides kollidiert.

Uebereinander angeordnet (XZ-Ebene) steht die Ritzelachse waagerecht in Y.
Der Motor laesst sich dann seitlich direkt anflanschen - dort ist Freiraum,
weil die Zangen das Bauteil mittig fassen.

LAGEPLAN (Greifer-Koordinatensystem, Blick in -Y)

    z
    |   +-------------------------------------------------+  Gehaeuse
 42 |   |  ===== Zahnstange 1 (oben) ===========[Steg]     |
 57 |   |        Teillinie oben       vvvv                 |
 67 |   |  -- Ritzelachse (in Y) --  (Ritzel)  ---> Motor seitlich
 77 |   |        Teillinie unten      ^^^^                 |
 92 |   |     [Steg]========= Zahnstange 2 (unten) ======  |
 95 |   +-------------------------------------------------+
        |  Flansch Backe 2                 Flansch Backe 1 |
       -x                                                 +x

Die beiden Zahnstangen ueberlappen sich in x nur im Verzahnungsbereich um das
Ritzel; dort trennt sie die Hoehe. Ihre Anschraubflansche sitzen an
entgegengesetzten Enden, kommen sich also nicht in die Quere.

Die Verzahnung ist als Trapezprofil ausgefuehrt (Ersatzgeometrie). Die
Tragfaehigkeit wird analytisch in mechanismus.py nachgewiesen.
"""
import os
import sys
from math import cos, pi, radians, sin

sys.path.insert(0, os.path.dirname(os.path.abspath(__file__)))

from build123d import Align, Axis, Box, Cylinder, Pos, Rot, fillet
import params as P

C = (Align.CENTER, Align.CENTER, Align.MIN)
CC = (Align.CENTER, Align.CENTER, Align.CENTER)
CU = (Align.CENTER, Align.CENTER, Align.MIN)

# ---------------------------------------------------------------- Ebenen in Z
# Die Hoehenkette wird von INNEN nach AUSSEN aufgebaut: Verzahnung -> Zahn-
# stange -> Funktionstraeger -> Verkleidung. Kein Glied ist gesetzt, jedes
# folgt aus dem davor. Fruehere Fassungen hatten H_KOERPER = 62 mm fest
# eingetragen; das war 13 mm mehr, als die Mechanik braucht.
Z_KOERPER = 40.0                           # Unterkante Schnellwechsler

# ---------------------------------------------------------------- Verzahnung
MODUL = P.MODUL
Z_RITZEL = P.Z_RITZEL
R_TEIL = P.R_TEILKREIS                     # 10,0 mm
B_ZAHN = P.B_ZAHN                          # 8 mm (Breite in Y)
H_KOPF = 1.00 * MODUL
H_FUSS = 1.25 * MODUL
H_ZAHN = H_KOPF + H_FUSS
D_WELLE = 8.0

# ---------------------------------------------------------------- Gehaeuse
GEH_X, GEH_Y = 124.0, 60.0
X_L, X_R = -GEH_X / 2, GEH_X / 2
WAND = 2.5

X_ZANGE = P.GREIF_ABSTAND / 2.0 + 8.0 + P.ZANGE_H / 2.0    # 47 mm

# Zahnstangen: Querschnitt SCHL_H (in Z) x SCHL_B (in Y)
SCHL_B = 16.0                               # = B_ZAHN + 2 x 4 mm Fuehrungsrand
# Hoehe des Zahnstangenkoerpers HERGELEITET aus zwei Bedingungen:
#
#  (a) Festigkeit. Die Backenkraft greift rund L_HEBEL unterhalb der
#      Zahnstange an. Das Kippmoment laeuft durch den Zahnstangenquerschnitt
#      am Steganschluss:  sigma = M / (SCHL_B * SCHL_H^2 / 6) <= Rp0,2 / S
#  (b) Gestaltung. Unter dem Zahnfuss muss mindestens noch einmal die volle
#      Zahnhoehe an Werkstoff stehen, sonst ist der Zahn nicht angebunden:
#      SCHL_H >= 2 * H_ZAHN
#
# Massgebend ist (b) - die Zahnstange ist also nicht kraft-, sondern
# gestaltbestimmt. Der aufgerundete Wert steht in SCHL_H.
RACK_RP02 = 260.0                           # MPa, EN AW-6082 T6
RACK_S = 2.0                                # - Sicherheit gegen Fliessen
L_HEBEL = 150.0                             # mm Zahnstangenmitte -> Backenmitte
_h_fest = (6 * P.F_ZANGE_AUSLEGUNG * L_HEBEL / SCHL_B / (RACK_RP02 / RACK_S)) ** 0.5
_h_gest = 2 * H_ZAHN
from math import ceil as _ceil
SCHL_H = float(_ceil(max(_h_fest, _h_gest)))   # auf volle mm aufgerundet
HUB = P.GREIFER_HUB

# Bauhoehe der Mechanik ab der Ritzelachse: bis zum Teilkreis, von dort um die
# Zahnfusshoehe in den Zahnstangenkoerper, dann dessen Hoehe.
H_MECH = R_TEIL + H_FUSS + SCHL_H
WAND_TRAEGER = 3.0                          # mm Decke/Boden des Funktionstraegers
H_MECH_GES = 2 * (H_MECH + WAND_TRAEGER)
# Zweite Bedingung: der Motor sitzt mit seinem Flansch am Traeger. Der
# NEMA-17-Flansch ist 42 mm hoch - mehr als die Mechanik braucht. Die Bauhoehe
# wird also NICHT von der Verzahnung bestimmt, sondern vom Motor. Kleiner ginge
# nur mit NEMA 14 (35 mm), der aber nur die 1,4-fache statt der geforderten
# 2,0-fachen Momentreserve haelt (siehe params.py).
H_MOTOR_GES = P.MOT_FLANSCH + 2 * WAND_TRAEGER
H_KOERPER = max(H_MECH_GES, H_MOTOR_GES)
Z_UNTEN = Z_KOERPER + H_KOERPER
T_FLANSCH = 10.0                            # M6 in Alu: 1,5 d Einschraubtiefe
Z_ZANGE_KOPF = Z_UNTEN + T_FLANSCH
T_ZANGE_KOPF = 10.0
Z_ZANGE = Z_ZANGE_KOPF + T_ZANGE_KOPF

# Ritzelachse waagerecht in Y, mittig im Gehaeuse
Z_ACHSE = Z_KOERPER + H_KOERPER / 2.0


# Teillinien liegen um den Teilkreisradius ueber bzw. unter der Achse.
# Der Koerper sitzt um die Fusshoehe weiter weg, die Zaehne ragen von dort
# um die Kopfhoehe an den Teilkreis heran.
Z_TEIL_O = Z_ACHSE - R_TEIL                 # 57,5
Z_TEIL_U = Z_ACHSE + R_TEIL                 # 77,5
Z_RACK_O = Z_TEIL_O - H_FUSS - SCHL_H       # Oberkante Zahnstange oben
Z_RACK_U = Z_TEIL_U + H_FUSS                # Oberkante Zahnstange unten

# Laengen: Koerper muss bei geoeffneten Backen im Gehaeuse bleiben
RACK_VON, RACK_BIS = -30.0, 50.0
ZAHN_VON, ZAHN_BIS = -22.0, 22.0            # Verzahnungsbereich um das Ritzel

# ---------------------------------------------------------------- Antrieb
MOT_FLANSCH = P.MOT_FLANSCH
MOT_L_GETRIEBE = P.MOT_L_GETRIEBE
MOT_L_MOTOR = P.MOT_L_MOTOR
MOT_L = P.MOT_L_GESAMT
Y_MOT = GEH_Y / 2                                            # Anbauflaeche

# ---------------------------------------------------------------- Squircle
# Die Aussenform ist eine Superellipse (Squircle):
#     |y/a|^n + |z/c|^n = 1
# n = 2 ergibt eine Ellipse, n -> unendlich ein Rechteck. Bei n = 4 entsteht
# die volle, weiche Form, die an Geraeten ueblich ist: fast rechteckige
# Flaechen mit stetig gekruemmten Ecken - anders als eine Verrundung, die
# zwischen Gerade und Kreisbogen einen Kruemmungssprung hat.
# Exponent: n = 4 ist die klassische Squircle-Form. Weil sich die Superellipse
# zu den Enden verjuengt, kostet ein kleines n Bauraum - der Antrieb muss ja
# hineinpassen. Gerechnet (siehe _halbachsen) ergibt sich die Bautiefe:
#     n = 4 -> 136 mm    n = 5 -> 127    n = 6 -> 122    n = 8 -> 117
# Gewaehlt ist n = 6: 14 mm schlanker als n = 4 und optisch noch deutlich vom
# Rechteck entfernt. Der Wert ist der einzige Stellhebel dieser Abwaegung.
SQ_N = 6.0                                  # Exponent der Superellipse
SQ_PUNKTE = 96                              # Stuetzstellen des Spline-Profils
                                            # (Flaechenfehler < 0,05 % gegen 240)

# Halbachsen HERGELEITET, nicht gewaehlt:
#   a  Baulaenge des Antriebs + Wand; der Antrieb muss vollstaendig hinein,
#      sonst steht wieder etwas heraus
#   c  Bauhoehe der Mechanik (2 Zahnstangen + Ritzel) bzw. Umkreis des
#      Motorflansches - der groessere Wert bestimmt
WAND_SQ = 6.0                               # mm Wandstaerke Alu, gefraest
WAND_VERK = 3.0                             # mm Wandstaerke Verkleidung, SLS-Druck


def squircle(a_p, c, a_m=None, n=SQ_N, punkte=SQ_PUNKTE):
    """Punkte einer Superellipse, in +y und -y unterschiedlich weit.

    a_m = a_p ergibt die symmetrische Form. Sind die Halbachsen verschieden,
    treffen sich beide Haelften bei y = 0 auf z = +-c. Dort verlaeuft die
    Superellipse waagerecht (dz/dy = 0), die Tangente ist also stetig - die
    Form bleibt an der Nahtstelle knickfrei.
    """
    from math import cos, sin, pi, copysign
    a_m = a_p if a_m is None else a_m
    aus = []
    for i in range(punkte):
        t = 2 * pi * i / punkte
        ct, st = cos(t), sin(t)
        a = a_p if ct >= 0 else a_m
        aus.append((copysign(abs(ct) ** (2.0 / n), ct) * a,
                    copysign(abs(st) ** (2.0 / n), st) * c))
    return aus


# ---------------------------------------------------------------- Gestaltung
# Der Antrieb wird nicht angeschraubt, sondern in einen angeformten Ausleger
# eingehaust, der mit grossem Radius in den Grundkoerper uebergeht. Auf der
# Gegenseite sitzt ein kuerzerer Ausleger fuer den Motortreiber - er macht die
# Form absichtsvoll und holt den Schwerpunkt naeher an die Flanschachse.
# Auslegerdurchmesser HERGELEITET: der NEMA-Flansch ist quadratisch, seine
# Ecken liegen auf dem Umkreis MOT_FLANSCH*sqrt(2). Der Ausleger muss diesen
# Umkreis aufnehmen, plus Wandstaerke fuer das Fraesen in Aluminium.
WAND_AUSL = 4.0                             # mm
AUSL_QUER = MOT_FLANSCH * 2 ** 0.5 + 2 * WAND_AUSL

# Squircle-Halbachsen aus Antrieb und Mechanik
# Der Antrieb kann erst NACH der Mechanik beginnen: die Zahnstangen belegen
# +-SCHL_B/2 um die Mittelebene. Diese Breite gehoert in die Halbachse.
Y_MOT_INNEN = SCHL_B / 2 + 3.0                              # Motorsitz  (+Y)
Y_BRE_INNEN = -(SCHL_B / 2 + 3.0)                           # Bremssitz  (-Y)
Y_TRAEGER = SCHL_B / 2 + 8.0                                # zentraler Traeger

# HALBACHSEN AUS DER EINSCHLUSSBEDINGUNG, nicht aus einer Summe.
#
# Eine Superellipse verjuengt sich zu ihren Enden hin. Am Ende des Motors ist
# die Schale also nicht mehr so hoch wie in der Mitte - eine simple Addition
# "Sitz + Antriebslaenge + Wand" liefert deshalb ein zu kleines Profil, in dem
# der Motor mit seinen Ecken in der Wand steckt. Genau das ist passiert.
#
# Richtig ist: jedes Einbauteil liefert einen Eckpunkt (y, z), den die INNERE
# Superellipse noch umschliessen muss:
#
#     (y/a)^n + (z/c)^n <= 1
#
# Nach a aufgeloest und ueber alle Einbauteile maximiert. Weil c von denselben
# Punkten abhaengt, wird beides iterativ bestimmt.
#
# Der Exponent n steuert dabei den Handel zwischen Form und Bauraum: je
# groesser n, desto rechteckiger das Profil und desto weniger verjuengt es
# sich - und desto schlanker darf es bei gleichem Inhalt sein.
Y_MOT_ENDE = SCHL_B / 2 + 3.0 + 1.0 + MOT_L                 # Aussenkante Motor
Y_BRE_ENDE = SCHL_B / 2 + 3.0 + 1.0 + P.BREMSE_L            # Aussenkante Bremse
SPIEL_VERK = 1.0                                            # mm Luft zum Einbau

#                     y            z                        Seite
EINBAU_P = [(Y_TRAEGER,     H_KOERPER / 2),                 # Funktionstraeger
            (Y_MOT_ENDE,    MOT_FLANSCH / 2)]               # Motor
EINBAU_M = [(Y_TRAEGER,     H_KOERPER / 2),                 # Funktionstraeger
            (Y_BRE_ENDE,    P.BREMSE_D / 2)]                # Haltebremse


def _halbachsen(n=SQ_N):
    """Innere Halbachsen (a+, a-, c), die alle Einbauteile umschliessen."""
    pkt = [(y + SPIEL_VERK, z + SPIEL_VERK) for y, z in EINBAU_P + EINBAU_M]
    c = max(z for _, z in pkt) + 0.1
    a_p = a_m = max(y for y, _ in pkt) + 0.1
    for _ in range(200):
        def loese_a(liste):
            a = 0.0
            for y, z in liste:
                rest = 1.0 - (z / c) ** n
                a = max(a, y / rest ** (1.0 / n) if rest > 1e-9 else 1e9)
            return a
        a_p = loese_a([(y + SPIEL_VERK, z + SPIEL_VERK) for y, z in EINBAU_P])
        a_m = loese_a([(y + SPIEL_VERK, z + SPIEL_VERK) for y, z in EINBAU_M])
        c_neu = c
        for (y, z), a in [(pkt[0], a_p), (pkt[1], a_p), (pkt[2], a_m), (pkt[3], a_m)]:
            rest = 1.0 - (y / a) ** n
            if rest > 1e-9:
                c_neu = max(c_neu, z / rest ** (1.0 / n))
        if abs(c_neu - c) < 1e-6:
            break
        c = c_neu
    return a_p, a_m, c


_A_P, _A_M, _C = _halbachsen()
SQ_C = _C + WAND_VERK
SQ_A_P = _A_P + WAND_VERK                                   # Antriebsseite
SQ_A_M = _A_M + WAND_VERK                                   # Bremsseite
SQ_A = max(SQ_A_P, SQ_A_M)                                  # fuer Nachweise
# Z-Halbachse: die Schale muss den Funktionstraeger mit Spiel umschliessen.
# Der NEMA-Flansch ist quadratisch und steht ACHSPARALLEL im Gehaeuse - nicht
# auf der Ecke. Massgebend ist deshalb MOT_FLANSCH/2, nicht die Diagonale.
# Die frueher angesetzte Diagonale hat die Verkleidung um 17 mm zu hoch
# gemacht; das war der groesste Einzelfehler in der Hoehenkette.
Y_AUSL_MOT = Y_MOT - 10.0 + MOT_L + 6.0     # Aussenkante Motorausleger
Y_AUSL_EL = 46.0                            # Laenge Elektronikausleger
R_AUSSEN = 10.0                             # Radius der senkrechten Aussenkanten
R_UEBER = 8.0                               # Radius am Uebergang zum Ausleger


# ================================================================ Bauteile
def gehaeuse():
    """Pos.4 - Funktionstraeger, EN AW-6082 T6, gefraest.

    WERKSTOFFGERECHTE TRENNUNG: nur was Kraft uebertraegt, ist aus Aluminium -
    Zahnstangenfuehrung, Ritzellagerung, Motorflansch, Verschraubung zum
    Schnellwechsler. Die Aussenform uebernimmt die Verkleidung (Pos.12) aus
    dem 3D-Druck; sie traegt keine Last und darf deshalb duennwandig sein.

    Ein massiver Squircle aus Aluminium waege 2,56 kg - der Greifer laege
    damit bei 83 %% der Robotertraglast. Getrennt sind es rund 0,8 kg.
    """
    p = Pos(0, 0, Z_KOERPER) * Box(GEH_X - 2 * WAND_SQ, 2 * Y_TRAEGER,
                                   H_KOERPER, align=C)
    p = fillet(p.edges().filter_by(Axis.Z), 6.0)

    # Motorflansch: Aufnahme fuer Getriebe und Zentrierung
    p += Pos(0, Y_MOT_INNEN, Z_ACHSE) * Rot(-90, 0, 0) * Cylinder(
        H_KOERPER / 2, 14, align=CU)
    p -= Pos(0, Y_MOT_INNEN, Z_ACHSE) * Rot(-90, 0, 0) * Cylinder(
        MOT_FLANSCH / 2 - 3, 20, align=CU)

    # Bremsflansch auf der Gegenseite, gleiche Bauart
    p += Pos(0, Y_BRE_INNEN, Z_ACHSE) * Rot(90, 0, 0) * Cylinder(
        H_KOERPER / 2, 14, align=CU)
    p -= Pos(0, Y_BRE_INNEN, Z_ACHSE) * Rot(90, 0, 0) * Cylinder(
        P.BREMSE_D / 2 + 0.2, 20, align=CU)   # Aufnahmebohrung, H7-Sitz

    # Fuehrungstaschen, je Zahnstange getrennt und in X begrenzt
    p -= Pos((RACK_VON + X_R) / 2, 0, Z_RACK_O) * Box(
        X_R - RACK_VON + 4, SCHL_B + 0.4, SCHL_H + H_FUSS + H_KOPF, align=C)
    p -= Pos((X_L - RACK_VON) / 2, 0, Z_TEIL_U - H_KOPF) * Box(
        X_R - RACK_VON + 4, SCHL_B + 0.4, SCHL_H + H_FUSS + H_KOPF, align=C)

    # Freiraum fuer die Stege zu den Backenflanschen
    for seite in (1, -1):
        x_m = seite * X_ZANGE
        p -= Pos(x_m, 0, Z_RACK_O + SCHL_H) * Box(
            26 + 2 * HUB + 2, SCHL_B + 0.4, Z_UNTEN - Z_RACK_O + 20, align=C)

    # Ritzelfreiraum und Lagerbohrung
    p -= Pos(0, 0, Z_ACHSE) * Rot(90, 0, 0) * Cylinder(
        R_TEIL + H_KOPF + 1.0, B_ZAHN + 2, align=CC)
    p -= Pos(0, 0, Z_ACHSE) * Rot(90, 0, 0) * Cylinder(
        D_WELLE / 2 + 0.1, 4 * Y_TRAEGER, align=CC)

    # Anschraubbild zum Schnellwechsler
    for i in range(4):
        a = radians(45 + 90 * i)
        p -= Pos(25.0 * cos(a), 25.0 * sin(a), Z_KOERPER - 5) * Cylinder(2.5, 20, align=C)
    return p


def verkleidung():
    """Pos.12 - Verkleidung, PA12 (SLS-Druck).

    Squircle-Profil (Superellipse, n = 4) als duennwandige Schale. Sie traegt
    keine Last, deshalb genuegen WAND_VERK Wandstaerke - im 3D-Druck ohne
    Mehraufwand herstellbar, waehrend dieselbe Form gefraest aus dem Vollen
    teuer und schwer waere.

    Oeffnungen: oben fuer den Schnellwechsler, unten fuer die Greiferzangen.
    """
    from build123d import Spline, make_face, extrude, Plane

    def schale(a_p, a_m, c, laenge):
        # Periodischer Spline durch die Stuetzstellen, KEIN Polygonzug.
        # Ein 240-Eck erzeugt 240 Regelflaechen; in der Zeichnung projiziert
        # jede davon eine eigene Kante, die Ansichten liefen schwarz zu.
        # Der Spline ergibt eine einzige Flaeche - und die STEP-Datei
        # beschreibt damit die Kurve, statt sie zu facettieren.
        k = Spline(*[(y, z) for y, z in squircle(a_p, c, a_m, punkte=SQ_PUNKTE)],
                   periodic=True)
        return extrude(Plane.YZ * make_face(k), amount=laenge / 2, both=True)

    p = Pos(0, 0, Z_ACHSE) * schale(SQ_A_P, SQ_A_M, SQ_C, GEH_X)
    p -= Pos(0, 0, Z_ACHSE) * schale(SQ_A_P - WAND_VERK, SQ_A_M - WAND_VERK,
                                     SQ_C - WAND_VERK, GEH_X - 2 * WAND_VERK)

    # Keine Freistellung fuer Motor oder Bremse: die Halbachsen sind so
    # bestimmt, dass beide von selbst hineinpassen (siehe _halbachsen). Eine
    # zusaetzliche Tasche wuerde die Schale nur durchbrechen - genau das ist
    # in der Fassung davor passiert, der Motor war durch das Loch zu sehen.

    # Durchbruch oben fuer den Schnellwechsler: nur durch die Deckflaeche,
    # Ø58 Zukaufteil plus 2 mm Fuge.
    z_deckel = Z_ACHSE - SQ_C
    p -= Pos(0, 0, z_deckel - 5) * Cylinder(
        58 / 2 + 2, (Z_KOERPER + 1) - (z_deckel - 5), align=C)

    # Durchbrueche unten fuer die Zangen. Sie muessen genau den Steg der
    # Zahnstange freistellen - vom Beginn des Stegs bis unter die Schale -
    # und den Backenhub nach beiden Seiten zulassen.
    z_oben = Z_RACK_O + SCHL_H                  # dort beginnt der obere Steg
    z_unten = Z_ACHSE + SQ_C + 1
    # In x nur so breit wie der Steg auf seinem Weg: von der geschlossenen
    # Stellung (x = X_ZANGE) bis zur offenen (x = X_ZANGE + HUB), je 13 mm
    # halbe Stegbreite plus 2 mm Fuge. Frueher war der Schlitz mittig auf
    # X_ZANGE und reichte damit bis an den Motor - man sah ihn durch die Fuge.
    x_von = X_ZANGE - 13.0 - 2.0
    x_bis = X_ZANGE + HUB + 13.0 + 2.0
    for seite in (1, -1):
        p -= Pos(seite * (x_von + x_bis) / 2, 0, (z_oben + z_unten) / 2) * Box(
            x_bis - x_von, SCHL_B + 10 + 4, z_unten - z_oben, align=CC)
    return p


def ritzel():
    """Pos.5 - Ritzel m=1, z=20, Achse waagerecht in Y."""
    p = Pos(0, 0, Z_ACHSE) * Rot(90, 0, 0) * Cylinder(
        R_TEIL - H_FUSS, B_ZAHN, align=CC)
    teilung = pi * MODUL
    dicke = teilung / 2.0 - 0.12                 # Flankenspiel
    UEBERLAPP = 0.6                              # Zaehne greifen in die Nabe
    for i in range(Z_RITZEL):
        w = 360.0 * i / Z_RITZEL
        r = R_TEIL + (H_KOPF - H_FUSS) / 2.0 - UEBERLAPP / 2.0
        p += Pos(r * cos(radians(w)), 0, Z_ACHSE + r * sin(radians(w))) * \
            Rot(0, -w, 0) * Box(H_ZAHN + UEBERLAPP, B_ZAHN, dicke, align=CC)
    p -= Pos(0, 0, Z_ACHSE) * Rot(90, 0, 0) * Cylinder(
        D_WELLE / 2, B_ZAHN + 2, align=CC)
    return p


def ritzelwelle():
    """Pos.6 - Ritzelwelle, im Gehaeuse gelagert, Abtrieb zum Getriebe."""
    # Endet buendig an der Anbauflaeche des Motors - der Getriebeabtrieb
    # kuppelt dort an, beide duerfen sich nicht durchdringen.
    y_p, y_m = Y_MOT_INNEN + 1.0, Y_BRE_INNEN - 1.0
    return Pos(0, (y_p + y_m) / 2, Z_ACHSE) * Rot(90, 0, 0) * Cylinder(
        D_WELLE / 2, y_p - y_m, align=CC)


def _zahnstange(oben, offen):
    """Zahnstange mit Steg und Anschraubflansch fuer eine Backe.

    oben=True  : obere Zahnstange, Zaehne nach unten, Backe bei +X
    oben=False : untere Zahnstange, Zaehne nach oben,  Backe bei -X
    """
    seite = 1 if oben else -1
    s = (HUB if offen else 0.0) * seite

    # Zahnunterkante (align=MIN). Der Zahn reicht vom Zahnfuss - der im
    # Koerper liegt - bis zum Kopfkreis am Ritzel. UEBERLAPP laesst ihn in den
    # Koerper eingreifen; beruehren sich beide nur tangential, verschmelzen
    # sie nicht und die Zahnstange bleibt in Einzelkoerper zerfallen.
    UEBERLAPP = 0.6
    if oben:
        z_koerper = Z_RACK_O
        # Zaehne ragen nach UNTEN zum Ritzel
        z_zahn = Z_TEIL_O - H_FUSS - UEBERLAPP
        x_von, x_bis = RACK_VON + s, RACK_BIS + s
    else:
        z_koerper = Z_RACK_U
        # Zaehne ragen nach OBEN zum Ritzel
        z_zahn = Z_TEIL_U - H_KOPF
        x_von, x_bis = -RACK_BIS + s, -RACK_VON + s

    p = Pos((x_von + x_bis) / 2, 0, z_koerper) * Box(
        x_bis - x_von, SCHL_B, SCHL_H, align=C)

    # Trapezzaehne zum Ritzel hin
    teilung = pi * MODUL
    dicke = teilung / 2.0 - 0.12
    n = int((ZAHN_BIS - ZAHN_VON) / teilung)
    for i in range(n + 1):
        xz = ZAHN_VON + i * teilung + s
        if not (x_von + 2 <= xz <= x_bis - 2):
            continue
        p += Pos(xz, 0, z_zahn) * Box(dicke, B_ZAHN, H_ZAHN + UEBERLAPP, align=C)

    # Steg nach unten zum Anschraubflansch
    x_mount = seite * X_ZANGE + s
    z_steg_von = z_koerper + SCHL_H if oben else Z_RACK_U + SCHL_H
    p += Pos(x_mount, 0, z_steg_von) * Box(
        26, SCHL_B, Z_UNTEN - z_steg_von, align=C)
    p += Pos(x_mount, 0, Z_UNTEN) * Box(30, SCHL_B + 10, T_FLANSCH, align=C)
    for dy in (-9, 9):
        p -= Pos(x_mount, dy, Z_UNTEN) * Cylinder(2.5, T_FLANSCH, align=C)
    return p


def zahnstange(seite, offen=False):
    """Pos.7 - Zahnstange mit Steg und Backenflansch (2x).

    seite = +1 : obere Zahnstange, Backe bei +X
    seite = -1 : untere Zahnstange, Backe bei -X
    """
    return _zahnstange(seite > 0, offen)
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

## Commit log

2026-09-18 Preliminary study: parametric gripper, FEM chain, motion simulation
    Exploratory build to find out what the task actually demands before planning
    it. Every deliverable runs as a script chain without a GUI, so one iteration
    means changing a value in cad/params.py and rerunning.
    - cad/ parametric design, variant comparison, renderings
    - fem/ analytical and numerical strength proof (gmsh + CalculiX)
    - sim/ working sequence and collision check (MuJoCo, ABB IRB 1600)
    - docs/ assembly drawing with BOM
    - onshape/ native FeatureScript build, API access over the browser session
    Two findings worth keeping:
    - The jaw is governed by stiffness, not strength. The strength proof gives a
    safet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
    [Bauteil_A.STEP, Bauteil_B.STEP, Bauteil_C.STEP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]
2026-09-18 Project plan, split of work and pitch video
    The preliminary study answered what the task needs; this is the plan for
    actually doing it. PLAN.md carries the technical decisions, the points
    breakdown from the course, the milestone plan against the two hard dates
    (interim report 26 Nov, final review 15 Jan) and the open questions.
    Gripper concept: 2-finger parallel gripper, one four-bar parallelogram per
    finger, driven by a servo through a self-locking screw. Topology follows the
    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
2026-09-18 Gripper concept: inspired by the Robotiq 2F-85
    The concept scene, the README and the plan now show where the design comes
    from: electric, two fingers, one four-bar parallelogram per finger so the pads
    stay parallel. Side by side with our own schematic, so it is visible what is
    taken over and what is not.
    Not taken over is the underactuated second phalanx. Its adaptive wrap is
    statically indeterminate in encompassing mode and adds nothing on two flat
    parallel faces.
    The product photo is Robotiq's, kept in shared/references/ with a source note
    so it is never mistaken for our own work. The local robotiq.jpg is ignored.
